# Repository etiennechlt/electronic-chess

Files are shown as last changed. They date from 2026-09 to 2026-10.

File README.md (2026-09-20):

# Échiquier électronique automatique à détection LC

Échiquier physique qui identifie chaque pièce (type et couleur) par un
résonateur LC passif logé dans sa base, arbitre les coups (roque,
prise en passant, promotion incluse), joue contre un moteur d'échecs
ou en ligne, et fonctionne sur batterie. Plateau fin de 44 cm et
21 mm d'épaisseur ; le déplacement des pièces par aimant sur portique
CoreXY est une base optionnelle qui se substitue au fond plat. Le
STM32G474 est maître, un ESP32-S3 sert de pont radio (WiFi, BLE vers
l'horloge à bascule séparée), le Raspberry Pi Zero 2 W est optionnel.

Architecture du système

## Principe de détection

Chaque pièce porte une bobine plate de 45 µH et un condensateur C0G
1 % de la série E12 qui fixe sa classe (12 valeurs, 217 à 613 kHz).
Chaque case excite en large bande par un front raide, écoute le
ringdown à travers l'entrefer, et classifie au plus proche voisin sur
des fréquences calibrées par pièce. L'aimant de pièce est en ferrite
dure, transparent au champ de mesure ; celui du chariot en néodyme.

Empilement vertical coté

Plan de fréquences des 12 classes

## Source de vérité unique

Toute valeur numérique du projet vient de
[`config/board.yaml`](config/board.yaml). Les grandeurs dérivées (les
12 fréquences, diamètres, courses, entrefer, autonomie) sont calculées
par la bibliothèque `chessboard_calc` et épinglées par les tests
contre la spécification. Le pas de case `p` est figé à 50 mm
(ADR 0010) ; tout reste paramétrique et le rapport compare toujours
40 et 50.

```bash
python3 -m venv .venv && .venv/bin/pip install -e ".[dev]"
.venv/bin/pytest                                        # les garde-fous
.venv/bin/python -m chessboard_calc report --pitch all  # tables dérivées
```

Le test de couloir (`tests/test_corridor.py`) verrouille la contrainte
`r_mobile + r_statique <= p/2` pour les 21 paires de classes : si une
édition du yaml la viole, la CI casse, car la partie se bloquerait dès
e2-e4.

## Plateau 8 x 8 (ADR 0010)

Un module plateau invariant (contreplaqué plus quatre quadrants 4 x 4
identiques, frontal analogique embarqué) posé dans une base fine ou,
plus tard, dans une base chariot avec le CoreXY et les ailes de
capture. Cerveau, carte puissance et cellules plates au fond de la
base, sur la même empreinte dans les deux bases. Horloge à bascule
séparée, en BLE. Choix et raisons dans la
[note 10](docs/notes/10-plateau-8x8-et-horloge.md).

| Plateau fin | Vue éclatée |
|---|---|
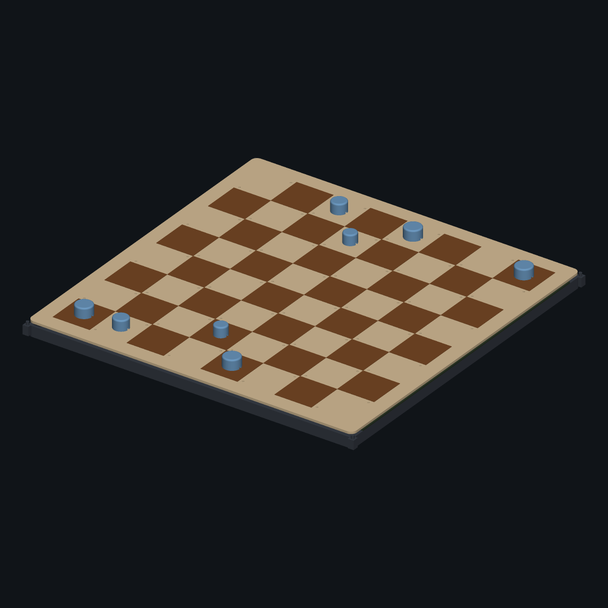
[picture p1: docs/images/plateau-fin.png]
Plateau fin
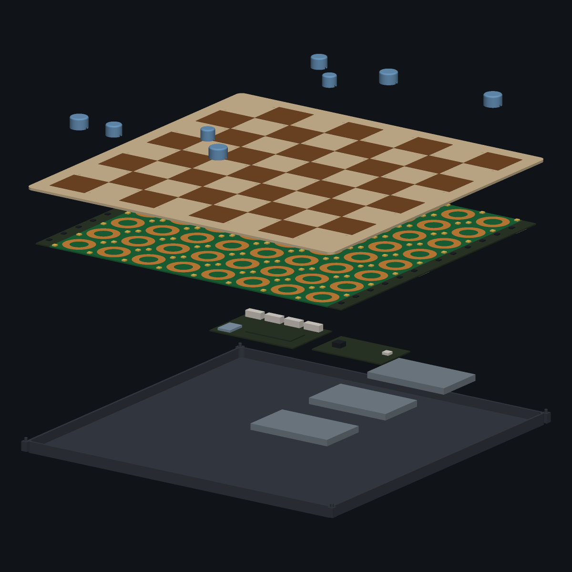
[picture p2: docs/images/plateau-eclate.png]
Vue éclatée
|  |  |

| Base chariot ouverte | Base chariot avec le module plateau |
|---|---|
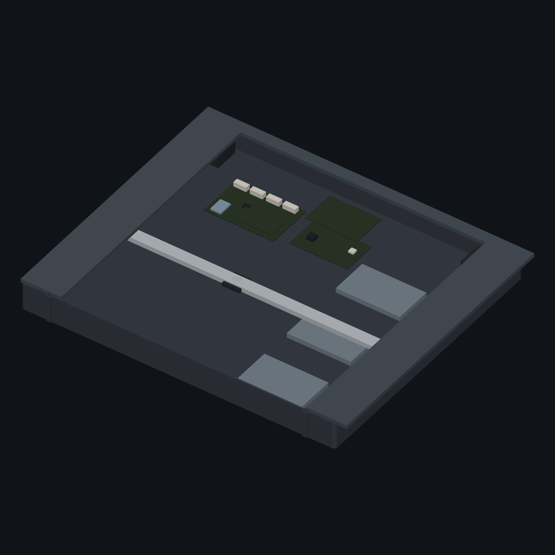
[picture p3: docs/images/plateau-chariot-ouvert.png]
Base chariot ouverte
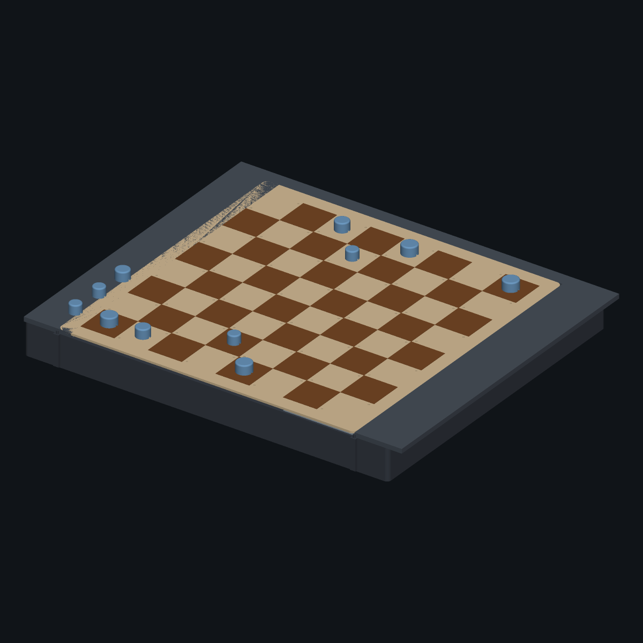
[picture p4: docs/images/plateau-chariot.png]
Base chariot
|  |  |

| Horloge à bascule | Horloge éclatée |
|---|---|
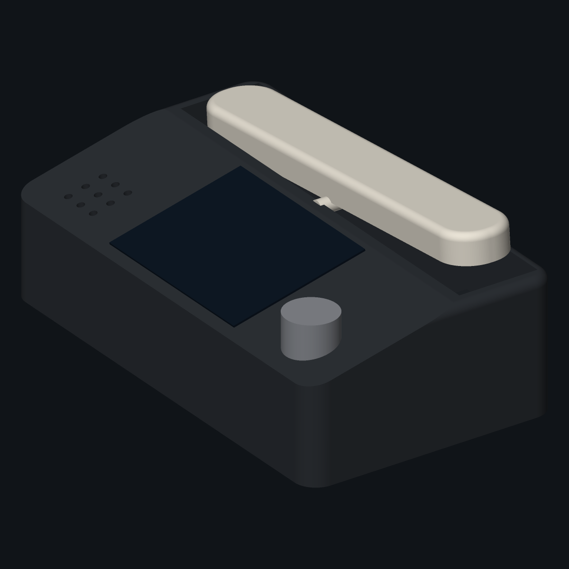
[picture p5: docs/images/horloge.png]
Horloge
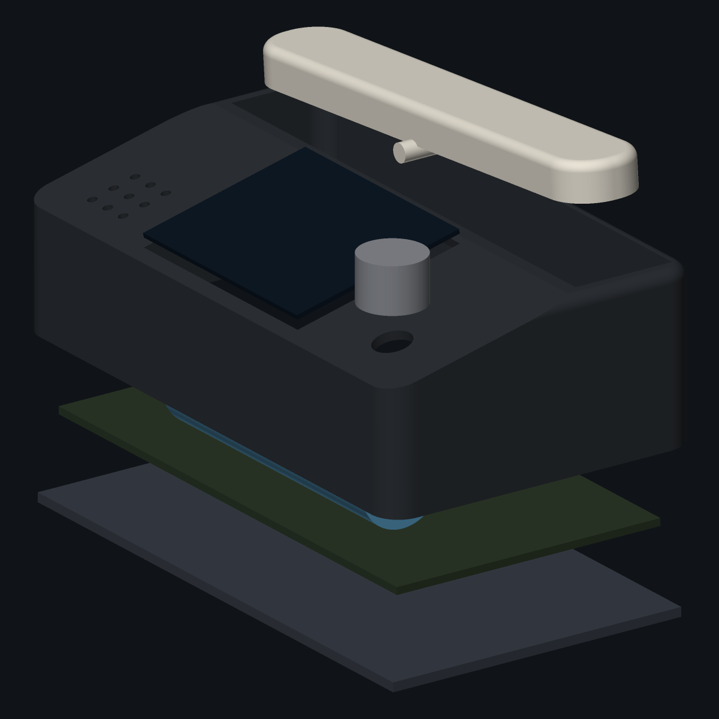
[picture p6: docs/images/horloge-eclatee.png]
Horloge éclatée
|  |  |

Vue 3D interactive (bases, éclaté, couches, noms au survol) :
`python mechanical/viewer.py` puis ouvrir `mechanical/exports/plateau-3d.html`.

| Quadrant 4 x 4 généré (`tools/quadgen`) |
|---|
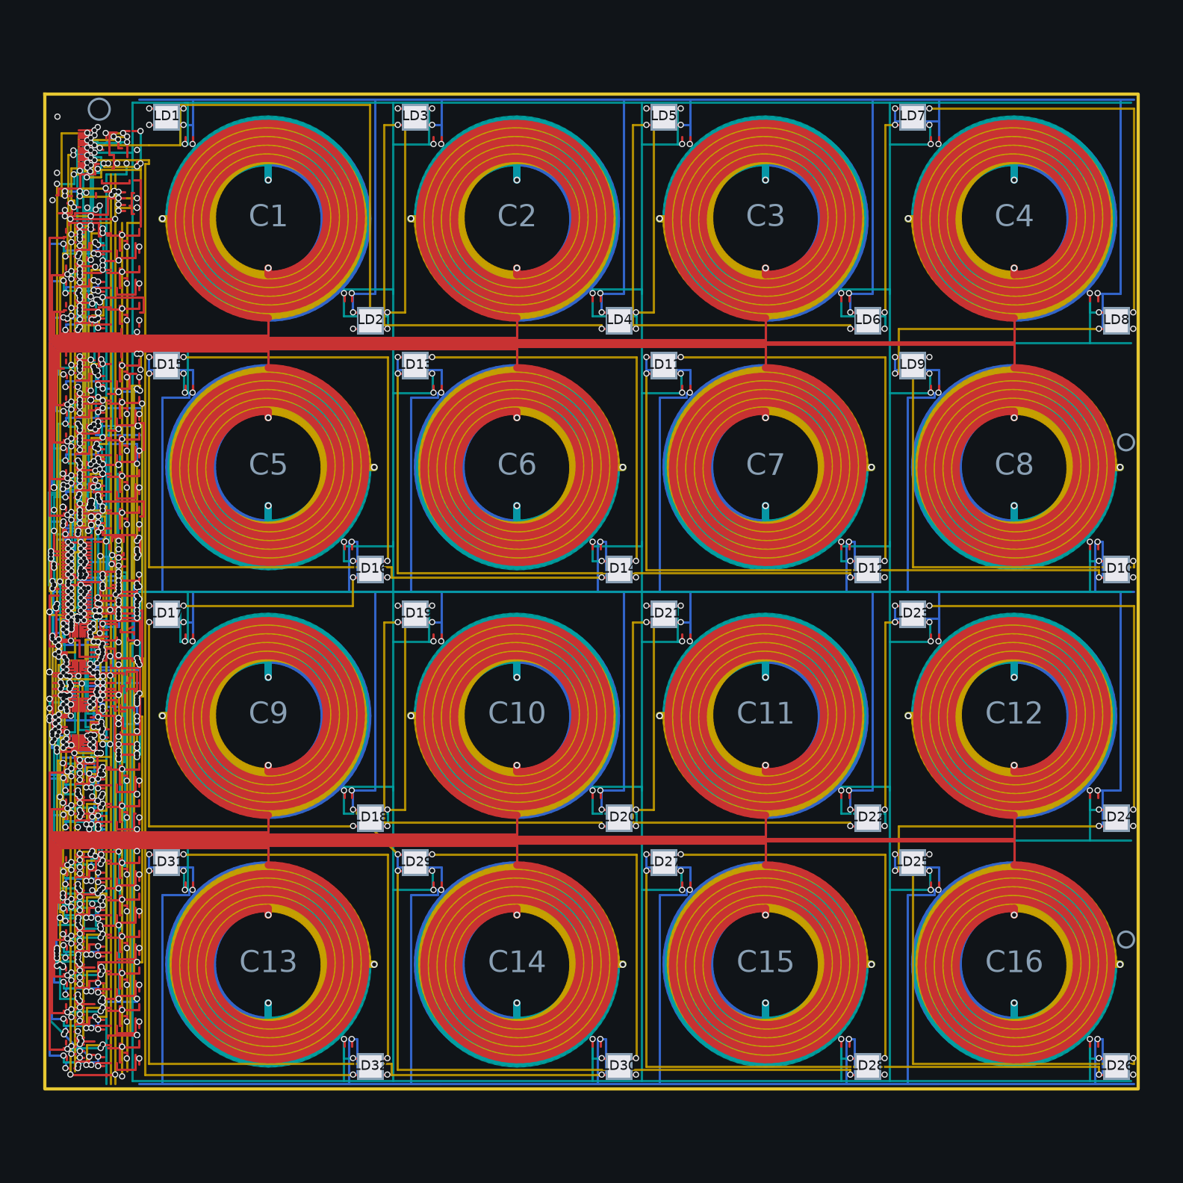
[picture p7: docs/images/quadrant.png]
Quadrant
|  |

Spirales, échappées vers la bande de frontal, 32 LED de camp et leur
distribution, connecteur FPC, et dans la bande de 20 mm le frontal
complet (16 cellules, deux ADG1607, décodeurs, chaîne AD8421 et
OPA2810) : [détails](hardware/quadrant/README.md). Le schéma est
dessiné feuille par feuille (fonction, composants et câblage dans la
[note 17](docs/notes/17-quadrant-fonction-et-cablage.md)) ; un
quadrant réduit 2 x 2, même circuit et même bus, sert de banc de mise
au point : [hardware/quadrant-2x2](hardware/quadrant-2x2/README.md).
Ce quadrant réduit et la [carte de banc](hardware/bench/README.md) qui
le pilote sont les deux cartes du plateau dont le routage est fermé,
donc les deux dont les gerbers sont commités
(`*-gerbers.zip`, produits par `tools/gerbers.py`, qui remplit les
pours avant de tracer et refuse toute carte à nets ouverts) : le banc
de la [note 20](docs/notes/20-tuto-banc.md) se commande tel quel. La
[carte analogique de maquette](hardware/mockup-2x2/analog-board/README.md),
gardée comme référence de la chaîne, est fermée elle aussi et porte
son archive. Ce qui se commande, avec quelles options et ce qu'il
manque aux autres cartes : la
[note 23](docs/notes/23-commande-jlcpcb.md). Ce qu'il faut acheter pour
monter le plateau (les 1 399 composants de quatre quadrants et d'un
cerveau, leur prix chez LCSC et chez Mouser, les paniers prêts à
téléverser) : la [fiche d'approvisionnement du plateau](docs/bom-plateau.md),
regénérée par `tools/bomagg.py`.

| Cerveau (STM32G474, 4 couches) | Puissance (3S, BQ24610, BQ76920) |
|---|---|
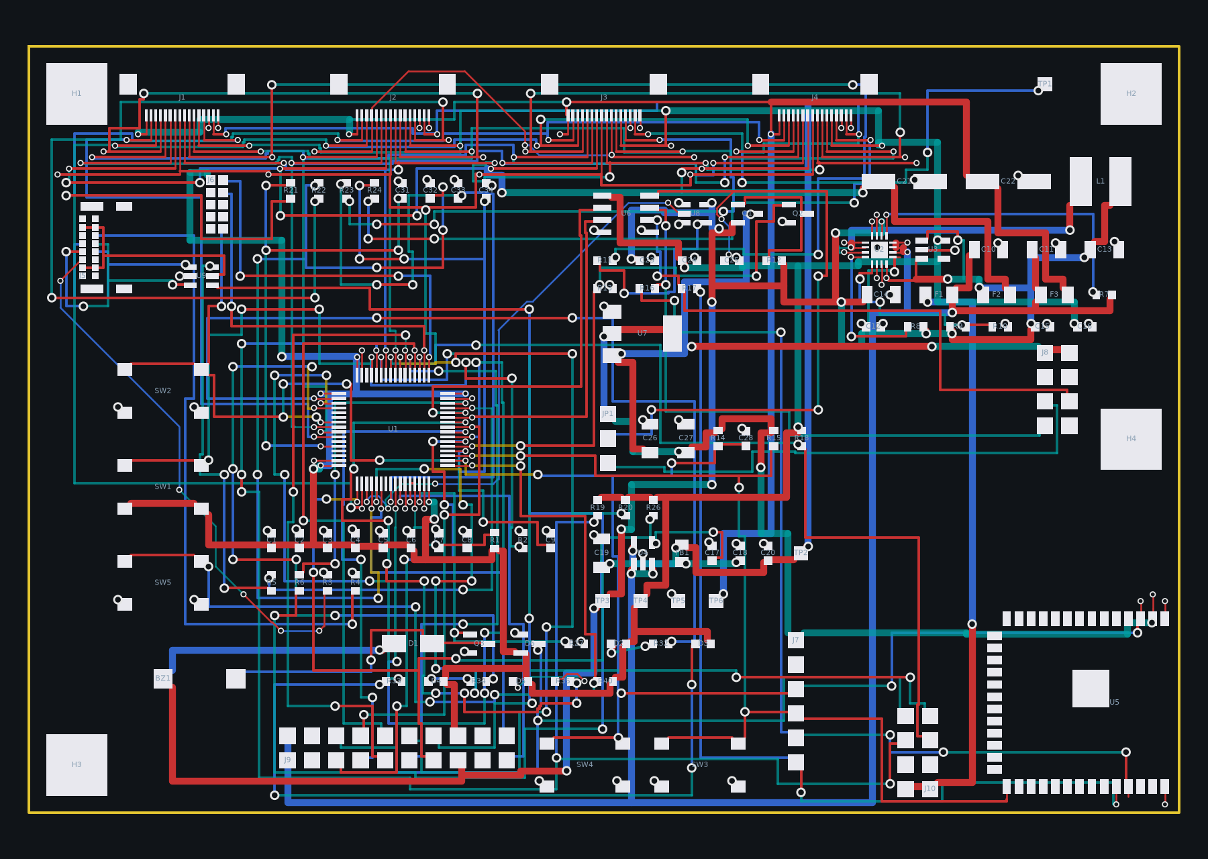
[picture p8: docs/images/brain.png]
Cerveau
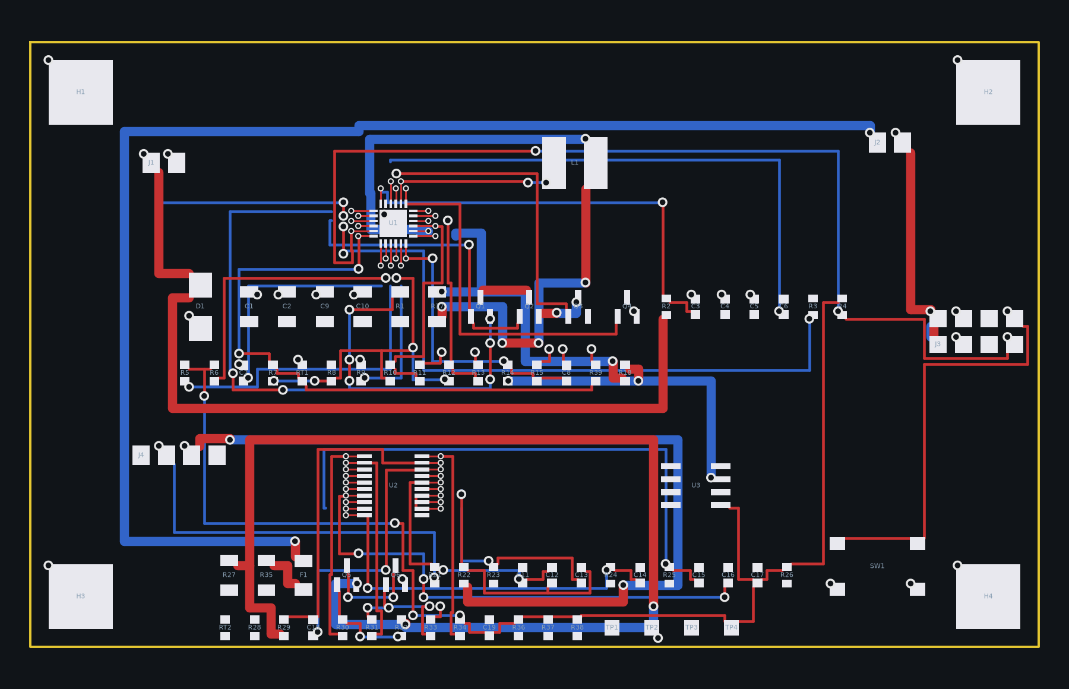
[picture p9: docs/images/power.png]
Puissance
|  |  |

| Moteurs (deux TMC2209, base chariot) | Horloge (ESP32-S3, 18650, écran) |
|---|---|
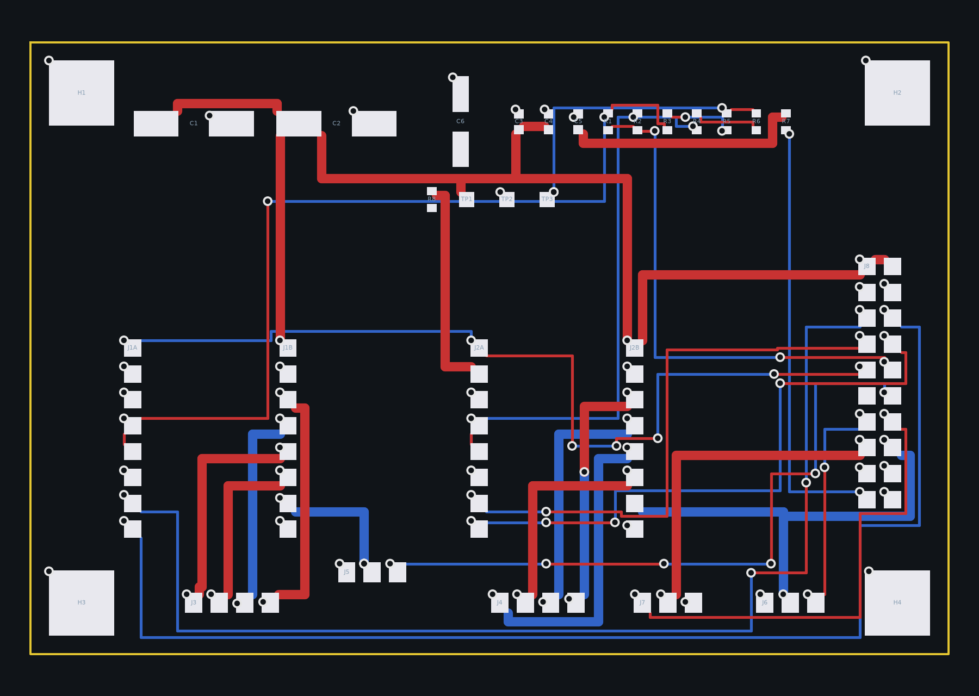
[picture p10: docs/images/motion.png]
Moteurs
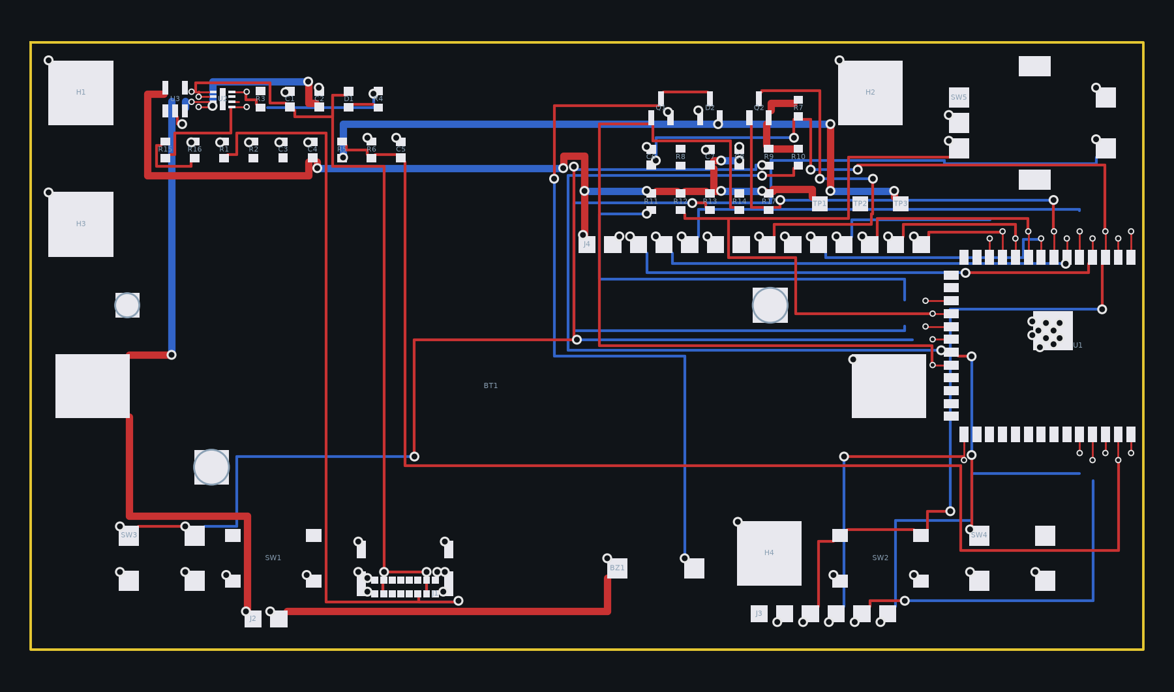
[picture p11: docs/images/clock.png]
|  |  |

Les quatre cartes sortent du générateur générique `tools/boardgen` ;
ce que le routeur laisse ouvert est listé dans le README de chaque
carte et résumé dans la [note 11](docs/notes/11-cartes-du-plateau.md).
Pour ouvrir, vérifier, simuler et tester : [note 13](docs/notes/13-revue-et-verification.md).

## Maquette 2 x 2 (phase 1, conçue, non construite)

La maquette a été conçue de bout en bout puis remplacée par le plateau
direct (ADR 0010) ; elle reste la référence de la chaîne analogique et
du routage ([guide](hardware/mockup-2x2/README.md),
[fiche d'approvisionnement](docs/bom-maquette.md)).

| Vue d'ensemble | Pièce de test éclatée |
|---|---|
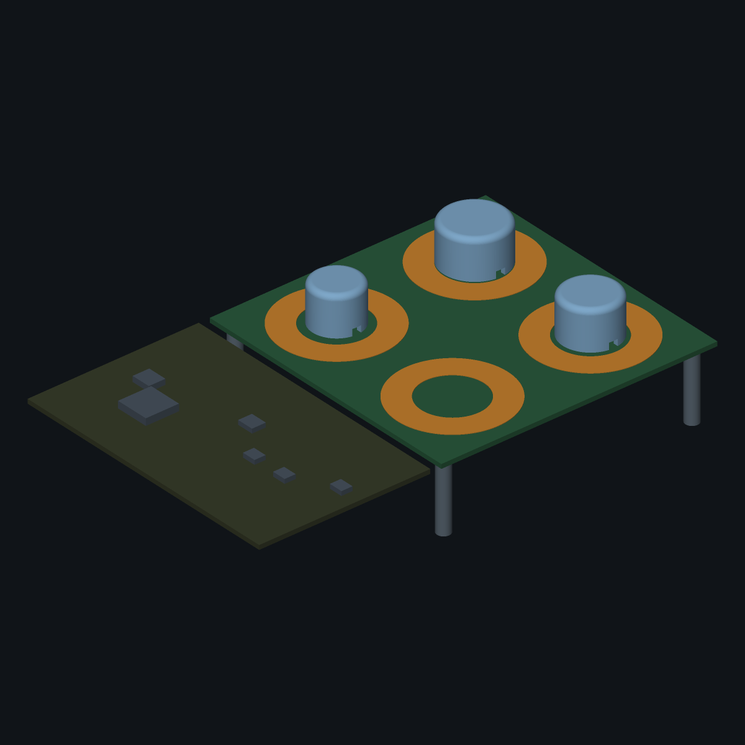
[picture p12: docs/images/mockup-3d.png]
Vue 3D de la maquette
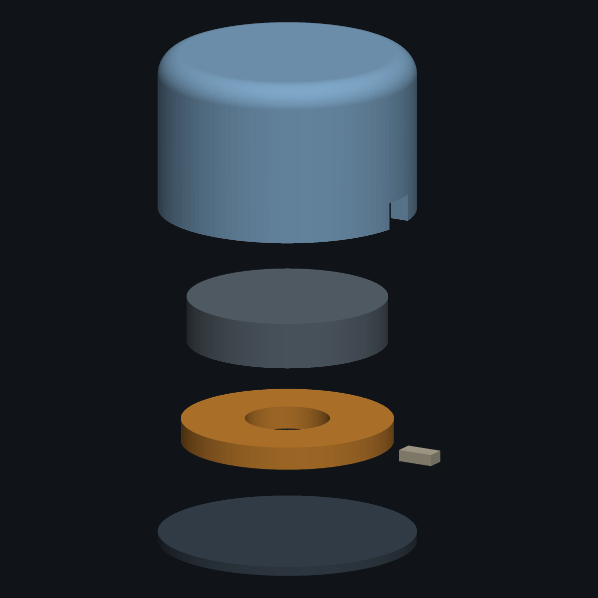
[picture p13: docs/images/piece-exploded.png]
Vue éclatée du puck
|  |  |

- **Carte bobines** (100 x 100, 4 couches, générée par
  [`coilgen`](tools/coilgen/)) : 4 spirales série de 5 tours par
  couche, 8 LED de camp WS2812B chaînées aux coins des cases (deux
  points lumineux par case à travers la surface en bois, ADR 0009).
  Son routage n'est pas fermé et son DRC porte 251 violations
  bloquantes : elle n'a pas d'archive de fabrication, et l'archive
  obsolète qu'elle portait a été retirée
  ([note 22](docs/notes/22-erreurs-de-conception.md), point 10),
  [détails](hardware/mockup-2x2/coil-board/README.md).
- **Carte analogique** (100 x 62, 2 couches, générée par
  [`analoggen`](tools/analoggen/)) : mux différentiel, AD8421,
  filtres Sallen-Key validés ngspice, buck forced-PWM contre LDO en
  cavalier, UART Pi isolée ; routage fermé, zéro élément non connecté
  et zéro erreur bloquante au DRC de KiCad, gerbers commités,
  [détails](hardware/mockup-2x2/analog-board/README.md).
- **Firmware** ([`firmware/board`](firmware/board/)) : les deux
  voies d'extraction du brief mesurées simultanément sur chaque
  ringdown, quatre quadrants par le bus de mux, calibration en flash,
  CSV sur le port série ; compile en CI. Pont radio et horloge en
  ESP-IDF ([`firmware/esp32`](firmware/esp32/)), protocole texte commun
  ([note 12](docs/notes/12-protocole.md)).
- **Mécanique** ([`mechanical/`](mechanical/README.md)) : plateau
  8 x 8 (module, bases, ailes), horloge, pucks de test, gabarits de
  bobinage, STL et STEP paramétriques, rendus et vue interactive.

| Carte bobines | Carte analogique |
|---|---|
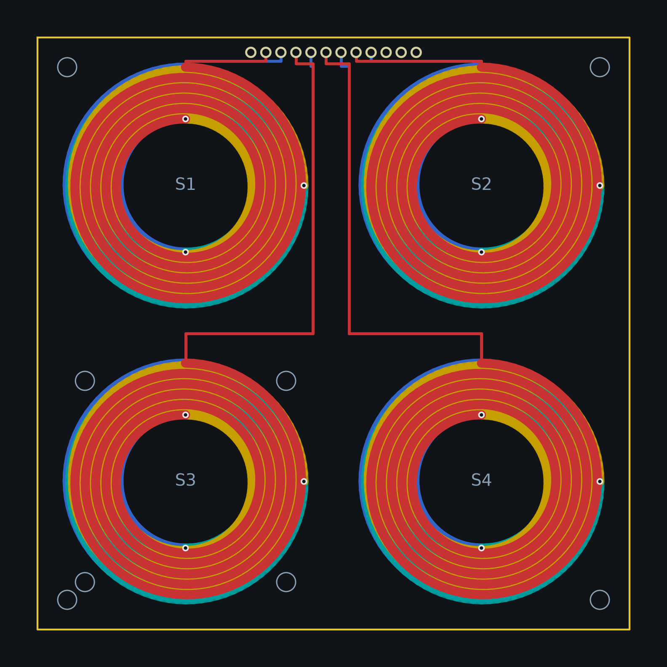
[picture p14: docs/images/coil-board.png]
Carte bobines
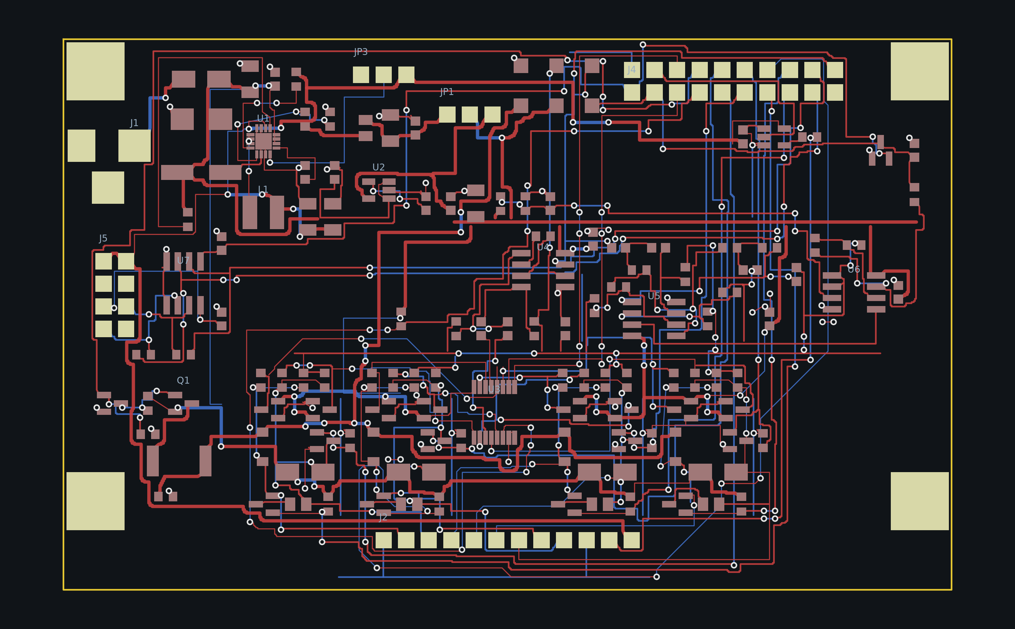
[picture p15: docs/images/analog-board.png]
Carte analogique
|  |  |

## Documentation

La base de connaissances du projet vit dans
[`docs/`](docs/README.md) : entrées par intention, notes de concepts
(mesure, architecture, générateurs, routeur, firmware), état de
référence, runbook de régénération et journal des décisions. Les
décisions formelles sont dans [`docs/adr/`](docs/adr/README.md).

## Arborescence

| Répertoire | Contenu | Phase |
|---|---|---|
| `config/` | `board.yaml`, source de vérité unique | 0 |
| `chessboard_calc/` | calculs paramétriques et garde-fous | 0 |
| `tools/coilgen`, `tools/analoggen` | générateurs KiCad des deux cartes de la maquette | 1 |
| `tools/drc.py`, `tools/plot.py`, `tools/gerbers.py` | DRC, tracés de faces et gerbers de fabrication, par le `pcbnew` de KiCad | 1 à 2 |
| `tools/fabcheck.py`, `tools/bomagg.py` | audit avant commande, et liste d'achat agrégée avec ses prix | 1 à 2 |
| `tools/quadgen`, `hardware/quadrant/` | générateur et projet KiCad du quadrant 4 x 4 | 2 |
| `tools/boardgen`, `hardware/{brain,power,motion,clock}/` | générateur générique et projets KiCad du cerveau, de la puissance, des moteurs et de l'horloge | 2 |
| `hardware/mockup-2x2/` | projets KiCad (`.kicad_pro` à ouvrir), gerbers, BOM, guides | 1 |
| `firmware/mockup/` | firmware Nucleo-G474RE (référence) | 1 |
| `firmware/board/` | firmware du cerveau : bus des quadrants, quatre ADC, 128 LED | 2 |
| `firmware/esp32/` | pont radio et horloge (ESP-IDF, NimBLE), protocole de la note 12 | 2 à 3 |
| `measurements/` | protocole, gabarits CSV, analyse | 1 |
| `mechanical/` | modèles CadQuery (plateau, horloge, pucks), rendus, vue 3D | 1 à 3 |
| `app/` | application, client Lichess sur le pont | 3 à 4 |

## État et décisions

Socle, calculs et CI livrés ; le plateau 8 x 8 est conçu directement
(ADR 0010) : yaml, géométrie, modèles 3D (STL et STEP dans
`mechanical/exports/`), quadrant complet, cerveau, puissance, moteurs et
horloge générés, firmware du cerveau compilé, pont et horloge écrits ;
premier lot de la phase 1 fait, la revue des cartes
([note 14](docs/notes/14-revue-des-cartes.md) : brochages relus, huit
erreurs corrigées dans les générateurs, DRC KiCad par `tools/drc.py`).
La suite est phasée : **phase 1, tout fonctionne sans chariot** (revue,
simulation, commande, bring-up, mesures, firmware, horloge, appli) ;
**phase 2, le chariot**. Feuille de route dans la
[note 07](docs/notes/07-etat-et-reste-a-faire.md). Les
décisions d'architecture et leurs justifications sont dans
[`docs/adr/`](docs/adr/README.md) ; conventions dans
[`CLAUDE.md`](CLAUDE.md) : code et commentaires en anglais,
documentation en français, aucune valeur dupliquée hors de
`board.yaml`.

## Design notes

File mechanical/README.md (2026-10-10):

# Mécanique (CadQuery)

Modèles paramétriques pilotés par `config/board.yaml`. Construction :

```bash
.venv/bin/python mechanical/build_all.py     # STL + STEP dans exports/ (versionnés)
.venv/bin/python mechanical/scenes.py        # rendus pour la doc (docs/images/)
.venv/bin/python mechanical/viewer.py        # vue 3D interactive (exports/plateau-3d.html)
.venv/bin/python mechanical/scenes.py --film-meshes media/pitch/commun/meshes  # maillages des films
```

Les films de présentation ([media/pitch](../media/pitch/README.md))
chargent les solides eux-mêmes : `--film-meshes` exporte en STL,
couche par couche et couleur par couleur, le plateau fin (base, trois
cellules, cartes, quatre quadrants, contreplaqué), la base chariot
sans son module et l'horloge avec sa barre à part, plus un
`manifest.json` (pivot de la barre). Ces maillages sont commités pour
rendre les films sans CadQuery ; les relancer après une modification
de la géométrie.

## Plateau 8 x 8 et horloge (ADR 0010)

- `plateau.py` : module plateau (contreplaqué à 128 points lumineux,
  quatre quadrants avec spirales, LED et bande de frontal), base fine,
  base chariot (CoreXY, ailes de capture, lisière), électronique sur
  empreinte commune, pièces. `assembly(cfg, gantry)` rend la liste des
  `Part` ; `exploded()` les écarte pour les vues éclatées.
- `clock.py` : boîtier de l'horloge à bascule (face inclinée, fenêtre
  d'écran, évidement de la barre, encodeur, grille, USB-C), fond,
  barre, bouton, intérieur. `horloge-boitier`, `horloge-fond` et
  `horloge-barre` s'impriment ; la barre est exportée à plat.
- `viewer_template.html` plus `viewer.py` : la vue interactive
  three.js, régénérée depuis les mêmes solides.
- Les cotes sont dérivées par `chessboard_calc/plateau.py` et
  épinglées par `tests/test_plateau.py` ; raisons dans la
  [note 10](../docs/notes/10-plateau-8x8-et-horloge.md).

Le rendu (`render_stl.py`) est un rasteriseur à tampon de profondeur
en numpy : occlusions exactes, sans OpenGL.

## Pièces de la maquette 2 x 2 (référence)

- `puck-<classe>-black` : pucks de test des 4 résonateurs bas de bande
  (pion, cavalier, fou, tour noirs). Alésage étagé par le dessous :
  logement bobine (2 mm), poche aimant ferrite ajustée, fente latérale
  pour le condensateur C0G et son accès de soudure. Impression tête en
  bas, 0,2 mm, sans support.
- `jig-core-d*` et `jig-washer-d*` : gabarits de bobinage, un par
  diamètre de bobine distinct. Le noyau donne le diamètre intérieur,
  les flasques l'épaisseur de 2 mm ; axe M3, encoche de sortie de fil.
  Monter le noyau dans une perceuse ou un petit tour, bobiner, coller
  au vernis, retirer la rondelle.
- `magnet-bracket-base` et `magnet-cup` : support d'aimant réglable
  sous la case S3 de la carte bobines. La platine se visse aux 4 trous
  M3 espacés de 34 mm, l'écrou central capture une vis M3 qui monte ou
  descend la coupelle porte-aimant (mesure 7 : distance de parking).

Quincaillerie : vis M3 x 8 (platine), M3 x 30 + 2 écrous (réglage),
entretoises M3 x 25 pour la carte bobines.

Les exports STL/STEP sont regénérés à la demande et ne sont pas
commités (`.gitignore`).

## Gabarit de perçage de la surface

`surface-template` reprend le contour de la carte bobines avec les
quatre trous de visserie et les deux points lumineux par case au
droit des LED de camp (ADR 0009). L'imprimer à plat (ou exporter le
DXF), le scotcher sur le contreplaqué et percer au travers ; les
points lumineux font `leds.light_hole_d_mm` (2,5 mm), à remplir
d'époxy translucide si l'on veut une surface affleurante.

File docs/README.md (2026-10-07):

# Documentation du damier électronique

Ce dossier est la base de connaissances du projet : tout ce qu'il faut
pour le comprendre, le régénérer, le commander et le reprendre à
froid. Les nombres font autorité dans `config/board.yaml` et dans les
tests qui les épinglent ; les documents expliquent, ils ne dupliquent
pas.

## Entrées par intention

- **Reprendre le projet à froid** : lire dans l'ordre
  [le principe de mesure](notes/01-principe-de-mesure.md),
  [l'architecture](notes/02-architecture-systeme.md),
  [le plateau 8 x 8 et ses choix](notes/10-plateau-8x8-et-horloge.md),
  [l'état et le reste à faire](notes/07-etat-et-reste-a-faire.md),
  puis le [journal](notes/09-journal.md) pour l'historique des choix.
- **Voir le plateau en 3D** : `python mechanical/viewer.py` génère la
  vue interactive (bases fine et chariot, éclaté, couches), les vues
  fixes sont dans `docs/images/plateau-*.png` et `horloge*.png`,
  méthode dans la [note 10](notes/10-plateau-8x8-et-horloge.md).
- **La maquette 2 x 2** (retirée du plan par l'ADR 0010, conservée
  comme référence de la chaîne analogique) : la
  [fiche d'approvisionnement](bom-maquette.md) et le
  [README de la carte analogique](../hardware/mockup-2x2/analog-board/README.md).
- **Le pilote simple** (07/10/2026) : une carte bobines passive
  100 x 100 et un shield soudé à la main, la
  [fiche du pilote](bom-pilote.md) dit ce qu'il réunit, ses trois
  options de shield et ce qu'il coûte.
- **Comprendre la mesure** :
  [principe](notes/01-principe-de-mesure.md), ADR
  [0001](adr/0001-lc-resonators-for-piece-identification.md) et
  [0007](adr/0007-frequency-extraction-dual-path.md), puis le
  [protocole M1 à M11](../measurements/protocol.md).
- **Savoir quoi faire ensuite** : la [note 07](notes/07-etat-et-reste-a-faire.md),
  feuille de route en deux phases (sans chariot d'abord, chariot ensuite).
- **Acheter les composants du plateau** : la
  [fiche d'approvisionnement du plateau](bom-plateau.md) donne la liste
  des 1 399 composants de quatre quadrants et d'un cerveau, ce qu'ils
  coûtent chez LCSC et chez Mouser, les neuf codes LCSC à corriger, les
  risques d'approvisionnement et les leviers chiffrés. Elle se regénère
  par `tools/bomagg.py`.
- **Commander les cartes chez JLCPCB** : la
  [note 23](notes/23-commande-jlcpcb.md) dit ce qui part et ce qui ne
  part pas, les fichiers et leur empreinte, les options écran par
  écran, la décision du cuivre interne, et ce qu'il manque pour passer
  un ordre d'assemblage plutôt que des cartes nues.
- **Ne pas refaire les erreurs déjà faites** : la
  [note 22](notes/22-erreurs-de-conception.md) reprend chaque erreur
  commise sur les cartes, ce qui l'a révélée, sa cause, sa correction
  et le contrôle automatique qui la rattrape désormais. À lire avant
  de toucher à un générateur ou de commander.
- **Baisser le coût des cartes** : la [note 16](notes/16-cout-des-cartes.md),
  état de la réflexion sur le quadrant et le format 100 x 100, avec
  les décisions à prendre avant tout devis.
- **Ouvrir, vérifier et tester les cartes** : la
  [note 13](notes/13-revue-et-verification.md) (KiCad, DRC, netlists,
  valeurs, simulation, commande, protocole de test) et le bilan de la
  revue des cartes, [note 14](notes/14-revue-des-cartes.md). L'état
  mesuré carte par carte, routage fermé ou non, est dans la
  [note 23](notes/23-commande-jlcpcb.md).
- **Savoir ce que le routage vaut devant les règles du métier** : la
  [note 21](notes/21-routage-et-regles-de-l-art.md) confronte les cartes
  générées aux règles de placement et de routage de la profession, avec
  la mesure de chacune par `tools/routing_audit.py` : ce qui est
  conforme, les écarts assumés (pas de plan continu sur In1 puisque la
  carte est le capteur, règle 2W dans une bande de 20 mm) et les deux
  points à corriger avant la commande.
- **Utiliser les skills embarqués** (analyseurs KiCad, SPICE, CEM,
  approvisionnement, mise en fabrication, commande JLCPCB, CadQuery) :
  la [note 15](notes/15-skills-embarques.md) dit lequel sert à quel
  lot et comment les mettre à jour.
- **Imprimer** : `python mechanical/build_all.py` écrit STL et STEP
  dans `mechanical/exports/` (non versionnés).
- **Comprendre le quadrant avant de le redessiner** : la
  [note 17](notes/17-quadrant-fonction-et-cablage.md), fonction, cycle
  de mesure, composants et câblage bloc par bloc.
- **Expliquer le projet à un non-spécialiste** : la
  [note 18](notes/18-facteur-q.md) (le facteur Q, avec les chiffres du
  projet), la [note 19](notes/19-cerveau-et-banc-nucleo.md) (le
  cerveau, le banc Nucleo, théorie contre réalité) et la
  [note 20](notes/20-tuto-banc.md) (le tuto du banc : quoi commander,
  comment assembler, comment tester) ; leurs schémas sont générés par
  `python -m docfig build`.
- **Envoyer ces explications à quelqu'un** : les mêmes trois textes
  existent en pages autonomes dans [`docs/pages/`](pages/), une par
  note, schémas embarqués et lisibles hors du dépôt :
  [le facteur Q](pages/facteur-q.html),
  [le cerveau et le banc](pages/cerveau-banc.html),
  [monter le banc](pages/tuto-banc.html). Elles sont générées par
  `python -m docfig pages`, des mêmes fonctions et du même yaml que les
  notes, donc jamais désynchronisées d'elles.
- **Modifier une carte** :
  [générateurs KiCad](notes/03-generateurs-kicad.md),
  [routeur et garanties](notes/04-routeur-et-garanties.md),
  [seeds et couloirs](notes/05-seeds-et-couloirs.md), puis le
  [runbook de régénération](notes/08-regenerer.md).
- **Toucher au firmware** : [note firmware](notes/06-firmware.md), le
  [README du firmware du cerveau](../firmware/board/README.md) (quatre
  quadrants) et celui de la [maquette](../firmware/mockup/README.md).
- **Lancer les mesures** : [protocole](../measurements/protocol.md),
  gabarits CSV et notebook dans `measurements/`.
- **Filmer le projet** : la série vidéo « Échec et Watt »
  ([bible](serie/README.md), [épisodes et scripts](serie/episodes.md),
  [tournage](serie/tournage.md), [montage](serie/montage.md)).

## Carte du dépôt

| Chemin | Contenu |
|---|---|
| `config/board.yaml` | source unique de toutes les valeurs |
| `chessboard_calc/` | calculs (fréquences, couloir, bobines, couplage, énergie) et CLI de rapport |
| `tools/coilgen/` | générateur complet de la carte bobines (spirales, LED, joint) |
| `tools/analoggen/` | générateur complet de la carte analogique (schéma, PCB routé, BOM, SPICE) |
| `tools/quadgen/` | générateur du quadrant 4 x 4 : spirales, échappées, LED, frontal complet (schéma, placement, routage) |
| `tools/boardgen/` | générateur générique et les quatre cartes du plateau : cerveau, puissance, moteurs, horloge |
| `tools/fabcheck.py` | audit de commande carte par carte : couches, empreinte de l'archive, couverture du BOM d'assemblage, verdict |
| `tools/docfig/` | schémas explicatifs de `docs/images/` (notes 18 et 19), dessinés depuis le yaml |
| `hardware/quadrant/`, `hardware/brain/`, `hardware/power/`, `hardware/motion/`, `hardware/clock/` | projets KiCad générés, BOM, placements, README de chaque carte |
| `hardware/quadrant-2x2/` | quadrant réduit 2 x 2 de mise au point, même circuit et même bus, schéma dessiné par feuilles |
| `hardware/bench/` | carte de banc, shield Nucleo-64 qui alimente et relie le quadrant 2 x 2 (note 19) |
| `hardware/mockup-2x2/` | artefacts générés : KiCad, gerbers, BOM JLC, guides |
| `firmware/board/` | firmware du cerveau (STM32G474, quatre quadrants, 128 LED) en CMSIS nu |
| `firmware/esp32/` | pont radio du cerveau et horloge (ESP-IDF, NimBLE), logique d'horloge testée sur PC |
| `firmware/mockup/` | firmware de la maquette Nucleo, référence |
| `mechanical/` | CadQuery : plateau 8 x 8 (module, bases, ailes), horloge, pucks, gabarits ; rendus et vue interactive |
| `measurements/` | protocole M1 à M11, gabarits CSV, analyse |
| `docs/adr/` | décisions d'architecture numérotées |
| `docs/notes/` | la présente base de connaissances |
| `docs/serie/` | série vidéo : bible, épisodes, tournage, montage |
| `.claude/skills/` | skills tiers embarqués (kicad-happy, pcba-design-skills, cad-skill), provenance dans `VENDORED.md` |
| `tests/` | une centaine de tests, dont le couloir bloquant en CI, l'empilement du plateau, le quadrant et la netlist de chaque schéma |

## Notes

| Note | Sujet |
|---|---|
| [01](notes/01-principe-de-mesure.md) | Principe de mesure : LC, ringdown, deux voies, classification |
| [02](notes/02-architecture-systeme.md) | Architecture système et budget de bruit |
| [03](notes/03-generateurs-kicad.md) | Générer du KiCad valide par script |
| [04](notes/04-routeur-et-garanties.md) | Le routeur maison et ses trois garanties |
| [05](notes/05-seeds-et-couloirs.md) | Seeds structurels et couloirs LED : la méthode |
| [06](notes/06-firmware.md) | Firmware : mesure, calibration, LED |
| [07](notes/07-etat-et-reste-a-faire.md) | État de référence et chemin vers le prototype réel |
| [08](notes/08-regenerer.md) | Runbook : tout régénérer |
| [09](notes/09-journal.md) | Journal des décisions et pivots |
| [10](notes/10-plateau-8x8-et-horloge.md) | Plateau 8 x 8, base interchangeable et horloge : les choix et leurs raisons |
| [11](notes/11-cartes-du-plateau.md) | Les cinq cartes du plateau : méthode, choix, revue avant fabrication |
| [12](notes/12-protocole.md) | Protocole plateau, pont radio, horloge (lignes texte, BLE) |
| [13](notes/13-revue-et-verification.md) | Ouvrir, vérifier, simuler, commander et tester les cartes |
| [14](notes/14-revue-des-cartes.md) | Revue des cartes de la phase 1 : constats, corrections, ce qui reste |
| [15](notes/15-skills-embarques.md) | Skills embarqués : lesquels, pour quel lot, comment les tenir à jour |
| [16](notes/16-cout-des-cartes.md) | Coût des cartes : quadrant, format 100 x 100, décisions à prendre avant de chiffrer |
| [17](notes/17-quadrant-fonction-et-cablage.md) | Quadrant : la fonction, les composants et leur câblage, base du schéma redessiné |
| [18](notes/18-facteur-q.md) | Le facteur Q, expliqué sans électronique |
| [19](notes/19-cerveau-et-banc-nucleo.md) | Le cerveau et le banc Nucleo, expliqués ; théorie contre réalité |
| [20](notes/20-tuto-banc.md) | Tuto du banc : quoi commander, quels composants, comment assembler et tester |
| [21](notes/21-routage-et-regles-de-l-art.md) | Le routage devant les règles du métier : conforme, écarts assumés, corrections |
| [22](notes/22-erreurs-de-conception.md) | Erreurs de conception des cartes, et le contrôle qui empêche chacune de revenir |
| [23](notes/23-commande-jlcpcb.md) | Commander chez JLCPCB : ce qui part, les options, ce qui manque pour l'assemblage |

Décisions formelles : [index des ADR](adr/README.md). Conventions de
contribution : `CLAUDE.md` à la racine (langue, typographie, source
unique, méthode).

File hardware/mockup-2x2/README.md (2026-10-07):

# Maquette 2 x 2 : commande, montage, mise en route

> Remplacée par l'ADR 0010 : la maquette n'est plus construite, le
> plateau 8 x 8 est conçu directement en quadrants. Ce dossier reste
> la référence de la chaîne analogique et du routage. Depuis le
> 07/10/2026 sa carte bobines, rendue passive, est la carte du
> **pilote simple** et la carte analogique son shield possible :
> voir la [fiche du pilote](../../docs/bom-pilote.md).

Deux cartes (ADR 0008) : la carte bobines (100 x 100, 4 couches,
passive) et la carte analogique (100 x 62, 2 couches, assemblée). Le
MCU est une Nucleo-G474RE du commerce reliée en nappes Dupont.

## 0. Ouvrir les cartes dans KiCad

Chaque carte a son fichier projet `.kicad_pro` à côté du `.kicad_pcb`,
généré en même temps que lui : c'est ce fichier qu'on ouvre, KiCad ne
sachant pas ouvrir une carte seule depuis son gestionnaire de projet.

```bash
kicad hardware/mockup-2x2/analog-board/analog-board.kicad_pro
kicad hardware/mockup-2x2/coil-board/coil-board.kicad_pro
```

Sous macOS ou Windows, double clic sur le `.kicad_pro` (ou KiCad,
Fichier, Ouvrir un projet). La carte s'ouvre avec les règles du
générateur déjà en place : classe de nets, largeurs de piste et vias
proposés au routage, minima du DRC. Le projet de la carte analogique
associe aussi son schéma, ouvrable depuis le même gestionnaire.

Trois choses à savoir :

- Les fichiers sont au format KiCad 7. KiCad 8 ou 9 les ouvre et
  propose la conversion au premier enregistrement.
- Symboles et empreintes sont embarqués dans les fichiers : aucune
  bibliothèque à installer, aucune table de bibliothèques à régler.
- KiCad réécrit le `.kicad_pro` en enregistrant (état des fenêtres) et
  crée un `.kicad_prl` local, ignoré par git. Une régénération remet
  le projet dans son état canonique.

Sans KiCad : les rendus `docs/images/analog-board.png` et
`docs/images/coil-board.png`, ou les zip de gerbers dans une
visionneuse.

## 1. Commander

### Carte bobines (8 à 15 EUR les 5, plus l'option cuivre interne)

`sh hardware/mockup-2x2/coil-board/export.sh` regénère la carte et
produit `coil-board-gerbers.zip` (commité avec son empreinte). JLCPCB :
4 couches, 1,6 mm, 1 oz externe, cuivre interne 1 oz en option (note 23,
paragraphe 3.1), pas d'assemblage : la carte est passive, les LED sont
coupées par `leds.fitted` dans le yaml.

### Carte analogique (~60 EUR les 5 dont 2 assemblées)

`analog-board/` contient le projet KiCad, `jlc-bom.csv` et
`jlc-cpl.csv`. JLCPCB : 2 couches, 1,6 mm, assemblage face top.
Important : les codes LCSC du BOM sont des candidats plausibles saisis
hors ligne ; l'outil de commande JLC rapproche aussi par référence
fabricant (MPN) et signale tout écart : vérifier chaque ligne dans
leur prévisualisation avant de payer, en particulier TPS62150RGTR,
AD8421ARZ, OPA2810IDR, 74HCT4052PW, ADuM1201ARZ. Les composants
introuvables en assemblage (souvent l'AD8421) se commandent chez
Mouser ou DigiKey et se soudent à la main (SOIC, facile).

### Le reste (~70 EUR)

Voir `docs/bom-maquette.md` : Nucleo-G474RE, condensateurs C0G des
résonateurs, fil émaillé, aimants ferrite et N42, contreplaqué sec 3 à 6 mm,
feutre, visserie, impression des pièces de `mechanical/`.

## 2. Assembler

1. Carte analogique : souder les traversants (jack, barrettes J2 J4
   J5, JP1 JP3) ; laisser R66 et R67 non montées (elles court-circuitent
   l'isolateur UART).
2. Carte bobines : souder la barrette coudée 1 x 10 mâle pointant vers
   le nord ; entretoises M3 x 25 aux quatre coins.
3. Emboîter la barrette dans le connecteur femelle coudé J2 de la
   carte analogique : les deux cartes sont coplanaires, broche 1 sur
   broche 1 (x = 38,57 mm sur les deux).
4. Support d'aimant : visser la platine sous S3, monter la coupelle
   sur sa vis M3.
5. Bobiner les 4 résonateurs (gabarits imprimés, fil 0,25 mm, tours
   par classe donnés par `python -m chessboard_calc report`), souder
   chaque condensateur C0G, coller bobine et aimant dans les pucks,
   feutre dessous.
6. Percer la planche de contreplaqué avec le gabarit `surface-template`
   (trous de visserie et points lumineux des LED), puis la poser sur les
   entretoises au dessus de
   la carte bobines.

## 3. Câbler la Nucleo

Nappes Dupont femelle-femelle de J4 vers la Nucleo (UM2505), table
générée depuis `config/board.yaml` (section `nucleo_pins`) :

| J4 | Signal | Nucleo |
|---|---|---|
| 1 | 3V3 | 3V3 |
| 2, 4, 19 | GND | GND |
| 3 | AMP_OUT | A0 (PA0), en pont vers A1 (PA1) pour la voie B |
| 5 | MUX_A0 | D3 (PB3) |
| 6 | MUX_A1 | D4 (PB5) |
| 7 | MUX_INH | D5 (PB4) |
| 8 | PULSE_EN | A2 (PA4) |
| 9 a 12 | DRIVE1..4 | D11 (PA7), D12 (PA6), D14 (PB9), D15 (PB8) |
| 13 a 16 | DAMP1..4_N | D6 (PB10), D7 (PA8), D9 (PC7), D10 (PB6) |
| 17 | MCU_TX | D8 (PA9) |
| 18 | MCU_RX | D2 (PA10) |
| 20 | INA_OUT | libre (oscilloscope) |

## 4. Mise en route

1. Flasher `firmware/mockup` (`make`, copier le .bin sur le lecteur
   NUCLEO). Console VCP 921600 bauds.
2. Alimenter le 12 V (JP1 côté LDO pour commencer, JP3 côté FPWM).
3. `h` puis `s` : quatre lignes CSV. Sans puck, amp_mv doit rester
   faible ; poser un puck doit faire apparaître sa fréquence.
4. Vérifier la voie B au générateur de fonctions sur AMP_OUT (voir
   `firmware/mockup/README.md`, points à vérifier).
5. Dérouler `measurements/protocol.md`.

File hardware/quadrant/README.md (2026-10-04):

# Quadrant 4 x 4 : carte de détection du plateau 8 x 8

Quadrant 4 x 4

Carte générée par `tools/quadgen` depuis `config/board.yaml`
(ADR 0010). Quatre exemplaires identiques dallent l'aire de jeu ; la
paire de droite est montée tournée de 180 degrés, ce qui laisse la
diagonale des LED inchangée et met la bande de frontal au bord extérieur.

## Ce que contient la carte

- 220 x 200 mm, 4 couches : 20 mm de bande de frontal à l'ouest
  (`plateau.quadrant.front_end_strip_mm`, couverte par la bordure de
  bois de même largeur), puis quatre colonnes de cases de 50 mm, soit
  4 p plus la bande sur 4 p.
- 16 spirales de détection (4 couches en série, 5 tours par couche,
  piste 1,6 mm), bornes empilées au nord des rangées impaires et au
  sud des rangées paires : chaque paire de rangées s'échappe dans le
  couloir qui les sépare (« bande »), huit voies par bande, vers les
  cellules du frontal, borne A sur F.Cu et borne B sur B.Cu.
- 32 WS2812B aux coins NO et SE de chaque case, un 100 nF chacune,
  vias latérales, chaîne de données sur In1 en serpentin (rangée 0 vers
  l'est, rangée 1 vers l'ouest, et ainsi de suite), grille 5 V sur
  In2, masse sur B.Cu (bords nord et sud, couloir médian) reliée au
  bus de la bande sur In1. Chaîne et retours sont routés par un A* sur
  grille de 0,2 mm contre tout le cuivre déjà posé.
- Connecteur FPC 16 broches 0,5 mm (Hirose FH12, 1,4 mm de haut, câble
  sortant à l'ouest), brochage dans `plateau.quadrant.link.pinout`.
- Trou de pion de centrage en bas de la bande, deux trous de fixation
  M3 au bord est, dans les zones libres de vias LED.

Le contrôle d'isolement exact (shapely) tourne à chaque build et le
projet KiCad porte les règles du générateur, vias d'éventail comprises ;
le DRC de KiCad se lance par `tools/drc.py` (module `pcbnew`, voir la
[note 14](../../docs/notes/14-revue-des-cartes.md)) ou après ouverture.
Le build échoue si une route de la chaîne LED, un retour d'alimentation
ou un net du frontal reste ouvert : la liste imprimée est ce qu'il reste
à fermer dans pcbnew.

## Le frontal de la bande

- 16 cellules de 7,4 mm en face de leur bobine, réparties de part et
  d'autre de chaque bande d'échappée : bleed 10 k vers VREF, 330 ohms
  et BAV99W (SOT-323) devant le mux, diode de bus B5819W et AO3400A
  d'excitation, SS34FL de roue libre vers VIN (SOD-123F, 1 mm de haut),
  B5819W de roue libre depuis la masse (point 1 de la
  [note 17](../../docs/notes/17-quadrant-fonction-et-cablage.md) : le
  courant de la bobine se referme par elle quand le N-FET s'ouvre, et
  R7 de 470 ohms coupe le rail en moins d'une microseconde), AO3401A et
  680 ohms d'amortissement pilotés directement par le décodeur (point 2,
  plus de rappel vers VIN), pulldown de grille 0402. Les colonnes de la cellule sont
  empilées à partir des cours réelles des empreintes et contrôlées
  contre le pas de 7,4 mm. L'entrée A arrive sur F.Cu à y - 0,6,
  l'entrée B sur B.Cu à y + 0,6 avec sa via.
- Zone médiane de 43,8 mm : 74HC4514 (excitation, inhibé par PULSE_EN
  à travers un 74LVC1G04) et 74HC154 (amortissement, validé par
  DAMP_EN_N), deux ADG1607 (bobines 1 à 8, 9 à 16, sorties en
  parallèle, un enable chacun, bus d'adresses A0..A2 partagé), AD8421
  G = 20, OPA2810 en Sallen-Key passe-haut et passe-bas, OPA2810 en
  tampon VREF et étage de sortie, écrêtage vers 3V3 et RC de sortie.
- Zone du milieu (43,8 mm entre les deux groupes de cellules, ancrée
  aux bandes d'échappée), du haut vers le bas : les deux décodeurs
  TSSOP empilés (le 74HC154 tourné de 180 degrés, adresses à l'ouest,
  sorties des bobines 1 à 11 à l'est, du côté des grilles), chacune de
  leurs vingt-quatre broches prolongée sous le boîtier jusqu'à un via
  (quatre colonnes au pas double des pastilles) ; le mux des bobines 1
  à 8, tourné de 270 degrés, ses seize entrées dessinées à la main en
  éventails (voies au pas de 0,6 mm, vias dans deux colonnes par côté) ;
  les deux amplificateurs côte à côte, broches échappées sous le
  boîtier ; le mux des bobines 9 à 16 et ses éventails. Tous les
  boîtiers à vias sont dans la bande ouest ; les passifs occupent la
  bande est, entre le rail 3V3 et le bord, par affinité.
- Zone du connecteur (25,7 mm) : FPC 16 broches, commutateur de rail
  d'impulsion (AO3401A, AO3400A, et la 10 ohms 2010 à côté), réserve
  10 µF, l'étage de sortie (OPA2810 avec ses résistances et son
  condensateur) pour que seul le signal filtré traverse la bande ; le
  point de test de sortie y reste, ceux de VREF et du bus d'excitation
  sont au pied de la bande, à côté de leur bus.
- Bus sur In1 côté est : 5VA, VREF, DRIVE_BUS, VIN et GND ; 3V3 et
  5V_LED sur In2. Les lignes de mesure M{k} vers les mux et les lignes
  de grille des décodeurs sont routées par le routeur A* multicouche
  depuis les vias dessinés à la main, un rip-up cherche le mur de
  chaque net resté en morceaux, puis un contrôle d'isolement exact
  valide toute la carte.
- Les vias d'empilement des bobines sont décalées radialement hors des
  bandes de spires (1,3 mm dans le creux ou au-delà du rayon extérieur,
  reliées par un tronçon radial) : posées sur le rayon même, elles
  recouvraient les spires des autres couches et court-circuitaient la
  bobine. La dernière jonction (In2 vers B.Cu) descend à 3,5 mm dans le
  creux et son tronçon radial porte le « net tie » (`quadgen:COIL_TIE`) :
  couches 1 à 3, vias et début du tronçon sur C{k}_A, deux pastilles
  B.Cu carrées qui se touchent, puis la suite du tronçon, l'arc
  d'entrée, la spirale de la couche 4 et l'échappée B sur C{k}_B, le
  tout à la largeur de spire. Aucun cuivre d'un net ne recouvre un trou
  de l'autre, ce que le DRC de KiCad exige même dans un net tie. Le
  schéma montre le même NT{k}.

Sorties du build : projet KiCad avec son schéma dessiné (feuille racine
`quadrant.kicad_sch` avec J1 et les blocs, puis `rails`, `cells-1` à
`cells-4`, `select`, `chain`, `leds`, fils tracés entre les composants,
fonction et câblage dans la note 17 ; aperçus dans le
[README du 2 x 2](../quadrant-2x2/README.md)), `bom.csv`, `jlc-bom.csv`
(lignes avec code LCSC), `jlc-cpl.csv`, `chain-spice.cir`.

## Régénérer

```bash
PYTHONPATH=tools .venv/bin/python -m quadgen build --render docs/images/quadrant.png
```

## Résultat du build

Généré par `python -m quadgen build` le 04/10/2026, avec les éventails
et les échappées dessinés à la main, le rip-up par recherche du mur et
la passe de finition partagée
([note 04](../../docs/notes/04-routeur-et-garanties.md)) :

| Bobines | LED | Segments | Vias | Raccords de la passe | Routes LED et alimentation ouvertes | Nets ouverts | Défauts d'isolement |
|---|---|---|---|---|---|---|---|
| 16 | 32 | 33171 | 946 | 15 | 0 | 24 | 0 |

Le build commité du 20/09 en laissait 47 ; les éventails des
multiplexeurs, les échappées sous boîtier des décodeurs et des
amplificateurs, l'étage de sortie ramené à la liaison, le 74HC154
tourné et le rip-up par recherche du mur ont fermé le reste, dans
l'ordre raconté par la note 04. Ce qui reste ouvert : douze lignes de
grille (DRIVE 2, 3, 10, 11, 12, 14, 15 et DAMP 2, 3, 9, 10, 16), neuf
lignes M (bobines 1, 2, 3 et 5 des deux côtés, 14 B), le retour du
filtre vers l'étage de sortie (LP_OUT), la référence en huit pièces et
un îlot du plan de masse. La cause est mesurée
voie par voie dans la note 04 : dans les rangées de la dernière cellule
de la bande 0 et sous les décodeurs, la bande de 20 mm offre à peu près
autant de voies que de lignes à faire passer, et un routeur séquentiel
n'emplit pas un couloir ; le rip-up trouve le mur de chaque net, deux à
cinq nets, et une levée sur deux est défaite faute de place pour ce
qu'elle soulève. Les options restantes (autoroutes à la main pour les
cellules lointaines, bande de 24 mm, six couches, cellule allégée) sont
des décisions de conception.

Aucune archive de fabrication : `tools/gerbers.py` refuse une carte au
routage ouvert.

DRC KiCad 7 (`tools/drc.py`, zones remplies) : 686 signalements, 31 éléments non connectés (les 24 nets ouverts ci-dessus), erreurs restantes : aucune ; avertissements sans effet sur la fabrication : lib_footprint_issues 199, silk_over_copper 199, silk_overlap 199, via_dangling 60, track_dangling 28, silk_edge_clearance 1. Le contrôle d'isolement exact du générateur ne signale aucun défaut. Les vias d'éventail et d'échappée font 0,45 mm (perçage 0,2 mm), dans les capacités standard de JLCPCB, à confirmer sur le devis.

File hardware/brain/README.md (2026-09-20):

# Cerveau : carte principale du plateau

Carte cerveau

Carte générée par `tools/boardgen` (module `brain`) depuis
`config/board.yaml` (ADR 0010). 120 x 80 mm, 4 couches : F.Cu
composants et signaux, In1 plan de masse, In2 alimentations et
signaux longs, B.Cu signaux. Elle vit au fond de la base, sur
l'empreinte commune aux deux bases.

## Blocs

- **MCU** : STM32G474RE soudé (LQFP-64), sans quartz (HSI plus CRS sur
  l'USB), boutons RESET et BOOT, connecteur SWD 2 x 5 au pas 1,27 mm
  (SWO et TDI laissés libres), USB-C en périphérique (USBLC6-2 en
  protection, 5,1 k sur CC, VBUS non utilisé : la carte se nourrit du
  pack). Le tableau des broches est `plateau.brain.mcu_pins` dans le
  yaml, relu contre la fiche technique dans la
  [note 14](../../docs/notes/14-revue-des-cartes.md) (quatre entrées ADC
  sur quatre convertisseurs distincts, PB8 sert de BOOT0, PG10 de NRST).
- **Liens quadrants** : quatre connecteurs FPC 16 broches (même
  brochage que le quadrant), bus d'adresses et d'enables partagé,
  quatre sorties analogiques vers quatre ADC à travers 49,9 ohms et
  1 nF, chaîne LED sérialisée d'un quadrant au suivant, tampon
  74AHCT1G125 à la source.
- **Alimentation** : fusible d'entrée, buck TPS62130 3 A à 2,5 MHz en
  PWM forcé (DEF haut) pour le 5 V, AP2112K pour le 3,3 V logique,
  LP2985 plus perle de ferrite pour l'îlot 5VA des quadrants, rail
  12 V d'impulsion (VIN) fusé avec sa réserve de 100 µF, rail LED fusé.
- **Communication** : UART tamponnée par un ADuM1201 (GND2 sur la masse
  commune : pas d'isolation galvanique tant que le module est sur la
  carte), TXD0 du module vers l'entrée VIA, sortie VOB vers RXD0, load
  switch P-FET sur le 5 V du module, régulateur AMS1117 pour
  l'ESP32-S3-WROOM-1, cavalier JP1 pour alimenter le côté module depuis
  l'ESP32 ou le Pi, embase Pi 2 x 4, embase de programmation ESP 1 x 6,
  boutons BOOT et EN. Le module est au bord est, son antenne dépasse de
  6 mm de la carte et sa zone de dégagement (la cour KiCad, 48 x 41 mm)
  occupe le coin sud-est : le quatrième trou de fixation est remonté à
  mi-hauteur du bord est.
- **Liens** : IDC 2 x 10 vers la carte moteurs (VBAT, STEP, DIR, EN,
  UART TMC, fins de course, servo, 5 V, 3,3 V), 2 x 4 vers la carte
  puissance (VBAT, I2C, état de charge, touche de réveil).
- **Interface** : buzzer 12 mm sur transistor, quatre LED d'état,
  bouton utilisateur, points de test.

## Hygiène de signal

Le plan de masse In1 est continu ; les sorties analogiques arrivent au
bord nord avec leur filtre RC juste devant le MCU ; le module radio est
au coin sud-est, le plus loin des connecteurs de quadrant ; le buck est
au coin nord-est avec sa boucle de commutation courte. Le routeur pousse
les longs signaux sur les couches internes (coût majoré sur F.Cu et
B.Cu) et ne perce jamais de via dans le trou d'une pastille traversante.
Point ouvert de la revue : le LP2985 de l'îlot 5VA (SOT-23-5) dissipe
0,5 W depuis VBAT pour les quatre frontaux, un boîtier à pad thermique
est proposé.

## Régénérer

```bash
PYTHONPATH=tools .venv/bin/python -m boardgen build brain --render docs/images/brain.png
```

Le contrôle d'isolement exact tourne à chaque build ; les nets que le
routeur n'a pas fermés sont listés et restent à finir dans pcbnew.

## Résultat du build

Généré par `python -m boardgen build brain` le 20/09/2026 :

| Composants | Segments | Vias | Raccords de la passe | Nets fermés | Nets ouverts | Défauts d'isolement |
|---|---|---|---|---|---|---|
| 113 | 1528 | 476 | 6 | 92 | 0 | 0 |

Ce qui a fermé la carte, dans l'ordre où il a fallu le trouver
([note 04](../../docs/notes/04-routeur-et-garanties.md)) :

- les éventails des quatre liens FPC dessinés à la main (voies de
  0,3 mm en escalier sur la face avant, un petit via au bout de chacune,
  les masses descendues au plan à leur moignon), la bande médiane
  descendue sous eux ;
- le bus des quadrants, les alimentations, VBAT, les quatre sorties
  analogiques et les deux lignes UART de l'isolateur routés en premier,
  quand la carte est vide ;
- le haul VBAT dessiné à la main sur la face arrière, du lien moteurs
  au fusible F1 par le bord sud puis une colonne à l'ouest du lien
  puissance ;
- chaque LED d'état placée à côté de sa résistance ;
- les masses descendues au plan avant les signaux, une garde de 0,1 mm
  autour des pastilles CMS ;
- le rip-up et reroutage des nets murés, puis la passe de finition
  partagée (six raccords).

DRC KiCad 7 (`tools/drc.py`, zones remplies) : 220 signalements, aucun élément non connecté, aucune erreur ; avertissements sans effet sur la fabrication : lib_footprint_issues 113, silk_overlap 52, via_dangling 27, silk_over_copper 23, silk_edge_clearance 3, track_dangling 2. Le contrôle d'isolement exact du générateur ne signale aucun défaut. Les vias d'éventail des boîtiers fins font 0,45 mm (perçage 0,2 mm), dans les capacités standard de JLCPCB.

## Fabrication

`brain-gerbers.zip` (quatre couches de cuivre, masques, sérigraphies,
pâte, contour, perçages PTH et NPTH, fiche de travail) et son
empreinte `brain-gerbers.sha256`, produits par
`/usr/bin/python3 tools/gerbers.py hardware/brain/brain.kicad_pcb` ;
`sha256sum -c brain-gerbers.sha256` dans ce dossier vérifie que
l'archive est celle de la carte commitée. Commande et options du
formulaire dans la [note 23](../../docs/notes/23-commande-jlcpcb.md) :
120 x 80 mm, 4 couches, ENIG (LQFP au pas de 0,5 mm, QFN, quatre FPC),
cuivre interne standard. La nomenclature d'assemblage (`jlc-bom.csv`,
`jlc-cpl.csv`) est complète en références, mais ses codes LCSC restent
à vérifier ligne par ligne avant tout ordre d'assemblage
([note 22](../../docs/notes/22-erreurs-de-conception.md), point 11).

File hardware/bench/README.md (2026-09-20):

# Banc Nucleo : shield d'alimentation et de liaison du quadrant 2 x 2

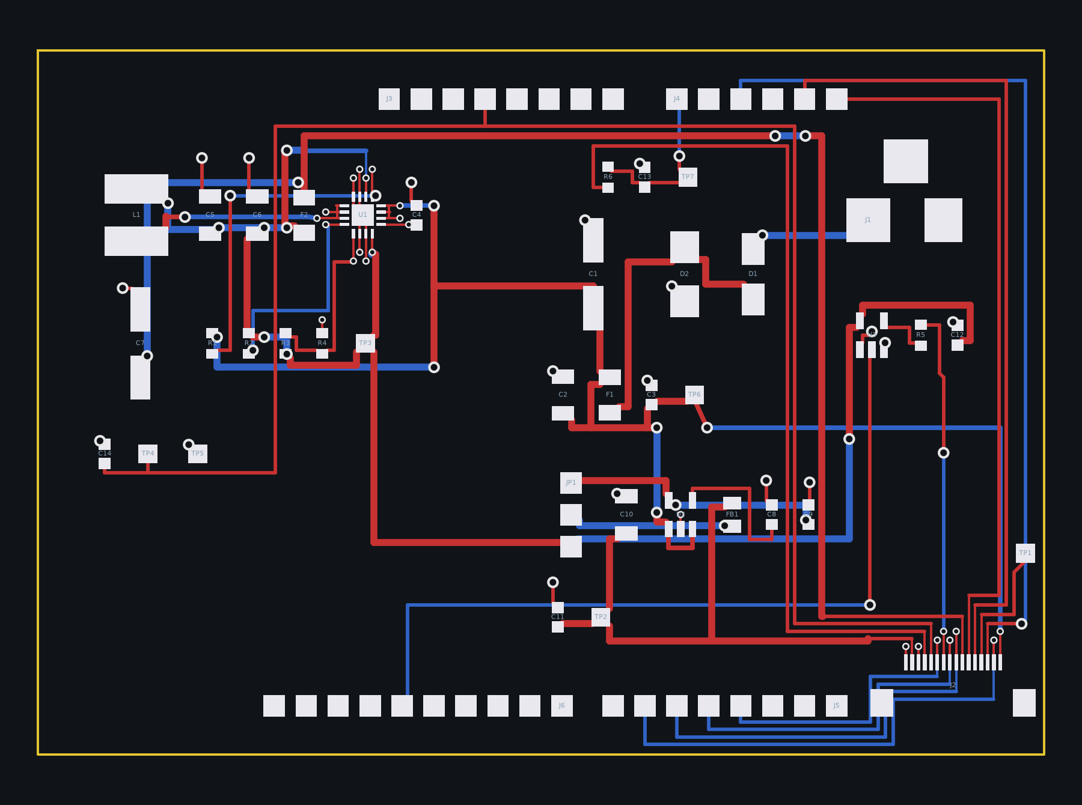
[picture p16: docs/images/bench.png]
Carte de banc


Les deux faces tracées par KiCad, pours remplis (`tools/plot.py`) :
la face composants avec sa sérigraphie, puis la face masse vue
retournée, comme on regarde la carte réelle.

Face composants

Face masse, vue retournée

Carte générée par `tools/boardgen` (module `bench`) depuis la section
`bench` de `config/board.yaml`, pour le banc de la
[note 19](../../docs/notes/19-cerveau-et-banc-nucleo.md) : une
Nucleo-G474RE (le MCU du cerveau, sa sonde et son port série) qui
mesure le quadrant réduit 2 x 2 (`hardware/quadrant-2x2/`) avec le
firmware du cerveau compilé en `make NUCLEO=1`. Le shield apporte au
quadrant ce que le cerveau lui aurait donné, et rien d'autre.
80 x 56 mm, 2 couches : composants et signaux sur F.Cu, plan de masse
sur B.Cu. Elle s'emboîte sur les quatre embases Arduino de la Nucleo
par des barrettes mâles montées côté cuivre, corps sous la carte.

## Blocs

- **Embases Arduino** (J3 alimentation, J4 analogique, J5 numérique 0 à
  7, J6 numérique 8 à 15) : positions prises sur l'empreinte officielle
  `Arduino_UNO_R3`, contour Uno affleurant au bord ouest, bande de
  11,4 mm à l'est pour le jack et la nappe. Le bus du quadrant est sur
  les broches de `bench.signals` : AMP_OUT (après RC) sur A0, PULSE_EN
  sur A2, MUX_A0 à A2 sur D3, D4, D5, MUX_EN_L sur A5, MUX_EN_H sur A4,
  DAMP_EN_N sur D6, LED_DIN sur D13. Le shield prend le 3,3 V et la
  masse de la Nucleo ; son 5 V ne remonte jamais vers elle (la Nucleo
  reste sur l'USB de sa sonde), VIN, 5V, IOREF, NRST et AREF restent
  ouverts.
- **Entrée 12 V** (J1 jack 5,5 x 2,1 mm, prise vers l'est) : SS34 en
  série contre l'inversion, SMBJ15A vers la masse, fusible 1 A, puis
  100 µF, 10 µF et 100 nF : la réserve du rail d'impulsion, comme sur
  le cerveau, dans la colonne centrale entre le jack et le buck.
- **Buck 5 V** (TPS62130, 2,2 µH, DEF haut : PWM forcé) : le rail des
  LED à travers un second fusible 2 A et 100 µF, et l'alimentation du
  tampon LED. Colonne ouest, là où le motif Uno laisse le shield vide.
- **Îlot analogique 5VA** : LP2985-5.0 depuis le 12 V, perle de
  ferrite BLM21PG221, 10 µF et 100 nF, comme sur le cerveau. Le
  cavalier JP1 choisit la source de 5VA_RAW : broches 1 et 2, le LDO
  (défaut) ; 2 et 3, le buck. C'est la comparaison LDO contre buck de la
  mesure M8.
- **Liaison quadrant** : J2, FPC 16 broches Hirose FH12 au brochage du
  quadrant (`plateau.quadrant.link.pinout`), au coin sud-est, nappe
  vers le sud, pastilles vers le nord ; tampon 74AHCT1G125 (3,3 V vers
  5 V) et 470 ohms devant LED_DIN, LED_DOUT sur un point de test ;
  49,9 ohms et 1 nF devant A0, le filtre du cerveau.
- **Points de test** : TP1 LED_END (au coin sud-est, contre le
  connecteur FPC), TP2 5VA, TP3 5V, TP4 3V3, TP5 GND, TP6 VIN, TP7 ADC1
  (AMP_OUT filtré). Le bus de commande (PULSE_EN, DAMP_EN_N, adresses
  du mux) se sonde sur les broches Morpho de la Nucleo, qui doublent
  chaque broche Arduino.

## Ce qui se soude à la main

Le tampon LED, le buck, l'inductance, le LDO, la perle, les diodes,
le jack et le connecteur FPC reprennent les références du cerveau,
code LCSC compris. Les passifs, les quatre barrettes Arduino (côté
cuivre), JP1 et les points de test n'ont pas de code : `jlc-bom.csv`
ne liste que les lignes qui en ont un, le reste se soude à la main ou
attend la passe de sourcing des autres cartes.

## Régénérer

```bash
PYTHONPATH=tools .venv/bin/python -m boardgen build bench --render docs/images/bench.png
/usr/bin/python3 tools/plot.py hardware/bench/bench.kicad_pcb --out docs/images
```

La seconde commande, avec le Python de KiCad, remplit les pours et
trace les deux faces en SVG (`bench-top.svg`, `bench-bottom.svg`).

`tests/test_bench.py` vérifie que chaque signal du bus est sur la
broche du cerveau (sauf DAMP_EN_N, déplacé de PC2 à D6 parce que PC2
n'atteint qu'un connecteur Morpho), que chaque broche d'embase porte
le net que dit le yaml, que la nappe reprend le brochage du quadrant,
et que chaque broche de barrette tombe sur la pastille de l'empreinte
Uno qu'elle représente.

## Routes manuelles

Le routeur seul laissait six nets ouverts et, au DRC de KiCad, une
trentaine de connexions manquantes que son propre bilan ne voyait pas
(couloirs de sortie des vias d'éventail sans cuivre, pistes finissant
sur le coin arrondi d'une pastille, voir la
[note 04](../../docs/notes/04-routeur-et-garanties.md)). La carte se
finit donc comme dans pcbnew, mais dans le générateur, par des routes
manuelles (`hand_routes` de `tools/boardgen/bench.py`) que chaque
build redessine et vérifie :

- **Éventail du FPC** (J2, seize pastilles au pas de 0,5 mm) : pas de
  via d'éventail dans le plan de masse ; chaque broche quitte son
  moignon sur une colonne de 0,2 mm et tourne à sa hauteur dans une
  voie de 0,3 mm, vers l'ouest pour 5VA, AMP_OUT1, 3V3 et 5V_LED, vers
  l'est pour MUX_EN_L, MUX_EN_H, LED_END et PULSE_EN, la broche la
  plus extérieure d'abord, la suivante une voie plus haut, si bien
  qu'aucune voie ne croise une colonne ; les fins de voies sont
  décalées pour laisser un via au bout de chacune. MUX_A0, MUX_A1,
  MUX_A2 et DAMP_EN_N prennent un petit via aux rangées d'éventail et
  passent en face arrière sous le connecteur, puis sous l'embase J5
  jusqu'à leurs broches ; VIN et LED_DIN1 de même vers le nord. Les
  deux broches de masse tombent au plan par un via au bout de leur
  piste d'envol.
- **Bande est** : MUX_EN_L monte en face avant jusqu'à la rangée de J4
  et entre dans la dernière broche par le bout de la rangée, MUX_EN_H
  passe au-dessus de la rangée, PULSE_EN monte en face arrière le long
  du bord (les deux se croiseraient sinon), LED_END rejoint TP1.
- **Face nord** : 3V3 monte à l'ouest de C9, passe sous les embases
  jusqu'à J3, continue vers l'ouest et redescend entre C6 et R3 vers
  TP4 et C14 ; 5V_LED et AMP_OUT1 suivent, une voie plus bas chacune,
  jusqu'au fusible des LED et au filtre de l'ADC, 5V_LED sautant en
  face arrière sur deux millimètres pour franchir la montée de 3V3 ;
  VIN traverse la carte en face arrière à mi-hauteur jusqu'à TP6.
- **Buck** : une barrette de 0,2 mm sur les bouts de moignons relie
  les trois pastilles SW, une autre les trois VIN (le routeur posait
  une piste de puissance le long d'une piste d'envol, à 0,10 mm du
  moignon voisin) ; SW part en face arrière vers l'inductance, VIN vers
  un via à l'est de C4 puis le condensateur d'entrée, la pastille 5 V
  du côté nord suit son couloir de sortie ; les quatre pastilles de
  masse du QFN sont pontées à son pad thermique.
- **Masses murées** : la pastille de masse du LDO (entre ses deux
  VIN) et celle de R4 ont un moignon et un petit via vers le plan.

Chaque route manuelle est vérifiée au build par le contrôle
d'isolement exact contre le cuivre déjà posé ; le routeur part de ces
routes et termine chaque net. Un déplacement de composant qui les
rendrait fausses fait échouer le build.

## Résultat du build

Généré par `python -m boardgen build bench` :

| Composants | Segments | Vias | Nets fermés | Nets ouverts | Défauts d'isolement |
|---|---|---|---|---|---|
| 43 | 263 | 72 | 29 | 0 | 0 |

Tous les nets sont fermés : le contrôle de connexité partagé des
générateurs (`tools/quadgen/connect.py`, chaque net une seule pièce de
cuivre, plan de masse compris, [note 04](../../docs/notes/04-routeur-et-garanties.md))
ne signale rien, `tests/test_bench.py` le vérifie à chaque exécution.

DRC KiCad 7.0.11 (`/usr/bin/python3 tools/drc.py
hardware/bench/bench.kicad_pcb`, zones remplies) : zéro erreur, zéro
élément non connecté ; 83 avertissements, tous ignorables : 43
chemins de bibliothèque des empreintes (la configuration de KiCad ne
connaît pas les bibliothèques par leur nom), 35 de sérigraphie
(références sur une ligne ou une pastille), 5 vias d'éventail du QFN
raccordés d'un seul côté (la route est partie en face avant).

## Gerbers de fabrication

`bench-gerbers.zip` se dépose tel quel chez le fabricant : 2 couches
(F.Cu, B.Cu), la pâte de la face composants, les deux sérigraphies,
les deux masques, le contour et les perçages Excellon séparés (PTH et
NPTH), plus le fichier de tâche `.gbrjob`. 1,6 mm, finition HASL sans
plomb ou ENIG ; les options de commande et la nomenclature sont dans
la [note 20](../../docs/notes/20-tuto-banc.md), section 3.

À côté de l'archive, `<carte>-gerbers.sha256` porte l'empreinte de la
carte tracée et celle de l'archive. À vérifier avant toute commande :

```bash
cd hardware/bench && sha256sum -c bench-gerbers.sha256
```

Options écran par écran, quantités et décisions à trancher : la
[note 23](../../docs/notes/23-commande-jlcpcb.md).

```bash
/usr/bin/python3 tools/gerbers.py hardware/bench/bench.kicad_pcb
```

Avec le Python de KiCad : l'outil remplit les pours d'une copie de la
carte avant de tracer (sans ce remplissage le plan de masse de B.Cu
sort vide), lit le jeu de couches sur la carte, et refuse d'exporter
tant qu'une pastille reste non connectée. Le dossier `gerbers/` qu'il
écrit n'est pas versionné ; l'archive l'est.

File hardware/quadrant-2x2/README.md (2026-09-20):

# Quadrant réduit 2 x 2 : banc de mise au point du quadrant

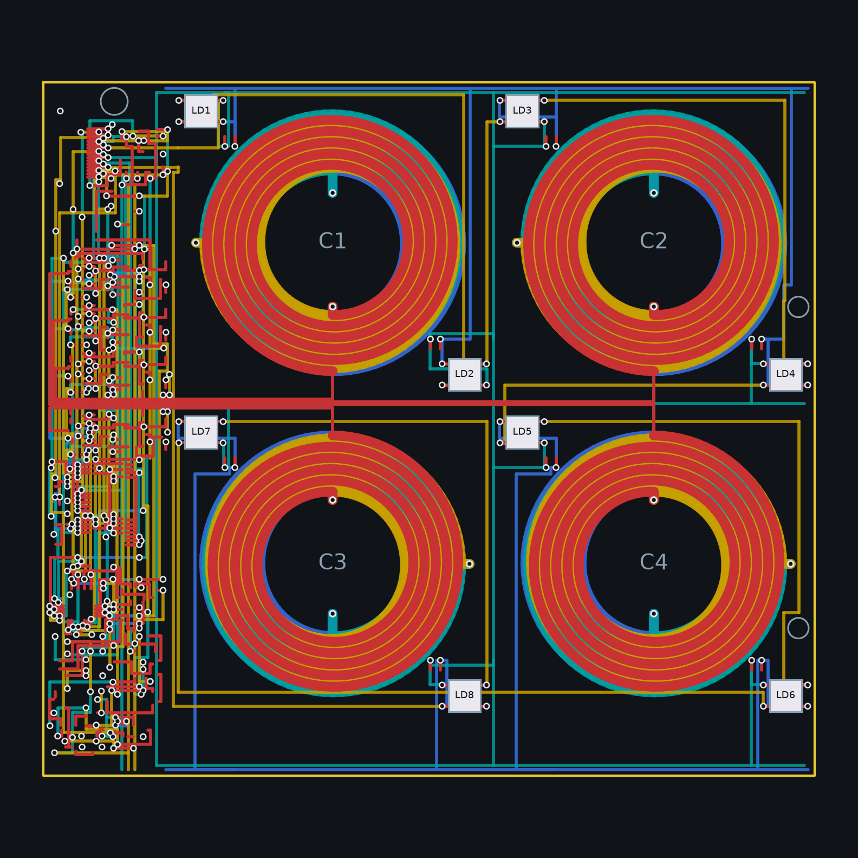
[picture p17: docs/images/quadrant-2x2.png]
Quadrant 2 x 2


Carte générée par `tools/quadgen` avec l'option `--reduced`, depuis
`config/board.yaml` (`plateau.quadrant.reduced`) : le même circuit, le
même bus de commande et le même firmware que le quadrant 4 x 4
([README](../quadrant/README.md)), avec quatre cases au lieu de seize.
Elle sert à valider le schéma, le frontal et la mesure sur une carte
courte et bon marché avant de commander les quadrants du plateau. La
fonction, les composants et leur câblage sont décrits bloc par bloc
dans la [note 17](../../docs/notes/17-quadrant-fonction-et-cablage.md).

## Ce que contient la carte

- 120 x 108 mm, 4 couches : 20 mm de bande de frontal à l'ouest
  (`plateau.quadrant.front_end_strip_mm`), deux colonnes de cases de
  50 mm, et un dépassement de 8 mm au sud (`reduced.strip_overhang_mm`)
  parce que la bande de frontal, avec une seule bande d'échappée et ses
  quatre cellules, est plus longue que deux cases.
- 4 spirales de détection identiques à celles du 4 x 4 (4 couches en
  série, 5 tours par couche, piste 1,6 mm), bornes au sud de la rangée
  0 et au nord de la rangée 1, échappées dans la bande qui les sépare
  vers les cellules du frontal, borne A sur F.Cu et borne B sur B.Cu.
- 8 WS2812B aux coins NO et SE de chaque case, un 100 nF chacune,
  chaîne de données en serpentin sur In1, grille 5 V sur In2, masse
  sur B.Cu le long des bords nord et sud (pas de couloir médian : dans
  un 2 x 2 le seul couloir est la bande d'échappée). La chaîne ne
  traverse jamais le frontal : elle entre et sort par deux voies
  dessinées au connecteur, une par sens.
- Masse du frontal : un plan sur B.Cu sous toute la bande, à la place
  de l'ancien bus sur In1. Les échappées des bobines le coupent en
  deux, quelques routes de la couche arrière y ouvrent des criques ;
  le build calcule les îlots réellement remplis et les fait recoudre
  ([note 04](../../docs/notes/04-routeur-et-garanties.md)).
- Connecteur FPC 16 broches 0,5 mm (Hirose FH12), brochage dans
  `plateau.quadrant.link.pinout`, identique au 4 x 4 : le cerveau ne
  voit pas la différence, `COILS_PER_QUADRANT` vaut 4 dans son firmware
  de test.
- Trou de pion de centrage en bas de la bande, deux trous de fixation
  M3 au bord est.

## Le frontal de la bande

Le même que sur le 4 x 4, avec les deux points de la note 17 intégrés :

- 4 cellules de 7,4 mm en face de leur bobine : polarisation 10 k vers
  VREF, 330 ohms et BAV99W (SOT-323) devant le mux, diode de bus B5819W
  et AO3400A d'excitation, SS34FL de roue libre vers VIN, **B5819W de
  roue libre depuis la masse** (le courant de la bobine se referme par
  elle quand le N-FET s'ouvre, quel que soit l'état du commutateur de
  rail), AO3401A et 680 ohms d'amortissement pilotés directement par
  le décodeur (plus de rappel vers VIN). Résistances de polarisation et
  d'écrêtage en 0603, amortissement en 0805, rappel de grille en 0402.
- Décodeurs 74HC4514 (excitation, inhibé par PULSE_EN à travers un
  74LVC1G04) et 74HC154 (amortissement, validé par DAMP_EN_N), sorties
  4 à 15 laissées libres ; un seul ADG1607 (bobines 1 à 4, enable
  MUX_EN_L) ; AD8421 G = 20, deux Sallen-Key OPA2810, tampon VREF et
  étage de sortie, écrêtage vers 3V3 et RC de sortie.
- Commutateur de rail d'impulsion AO3401A commandé par un AO3400A,
  **R7 de 470 ohms** pour que le rail se coupe en moins d'une
  microseconde après PULSE_EN, avant la fenêtre d'écoute ; 10 ohms
  2010 vers le bus des cellules.

## Le schéma

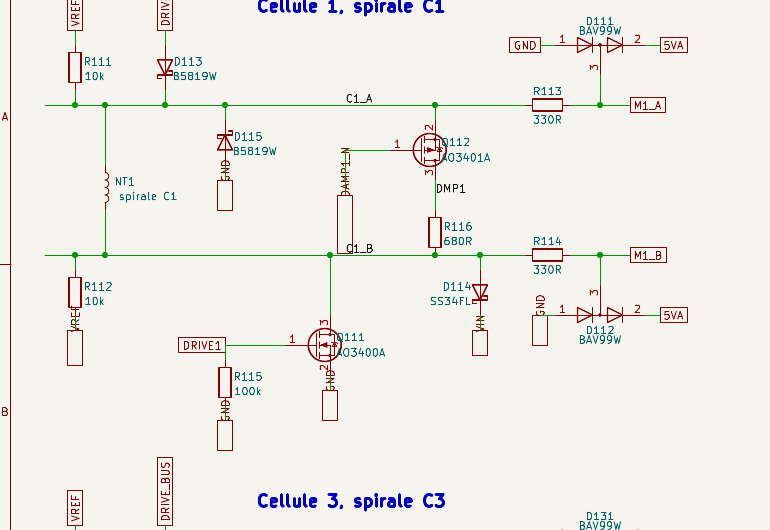
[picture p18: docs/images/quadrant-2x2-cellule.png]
Cellule de bobine, feuille cells-1


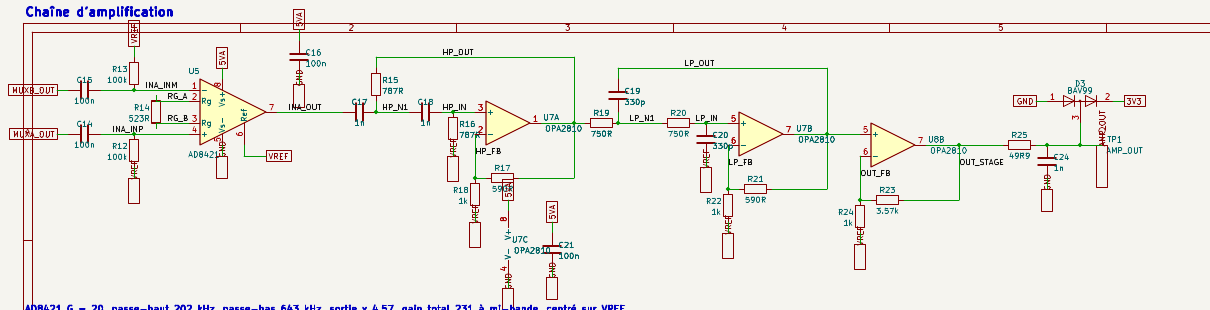
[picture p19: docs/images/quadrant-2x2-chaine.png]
Chaîne d'amplification, feuille chain


`quadrant-2x2.kicad_sch` est la feuille racine (connecteur J1 et les
blocs) ; les feuilles `rails`, `cells-1`, `select`, `chain` et `leds`
dessinent chaque bloc avec ses fils, une étiquette globale pour les
rails, le bus d'adresse et les nets partagés entre feuilles, une
étiquette locale pour les nets internes. Le dessin est vérifié contre
le circuit à chaque build et la netlist relue par `kicad-cli` est
comparée au circuit en test (`tests/test_drawn_schematic.py`).

Sorties du build : projet KiCad avec ses six feuilles, `bom.csv`,
`jlc-bom.csv` (lignes avec code LCSC), `jlc-cpl.csv`, `chain-spice.cir`.

## Résultat du build

Généré par `python -m quadgen build --reduced` (18/09/2026) :

| Bobines | LED | Segments | Vias | Nets ouverts | Pastilles ouvertes | Défauts d'isolement |
|---|---|---|---|---|---|---|
| 4 | 8 | 8706 | 371 | 0 | 0 | 0 |

DRC KiCad 7 (`tools/drc.py`, zones remplies) : 395 signalements,
**zéro erreur et zéro élément non connecté**, contre 117 éléments non
connectés le matin du même jour et sept après le reroutage. Le compte du
build et celui de KiCad disent la même chose, c'est ce que permet la
comptabilité de connexité partagée de la
[note 04](../../docs/notes/04-routeur-et-garanties.md). Avertissements
sans effet sur la fabrication : silk_overlap 151, lib_footprint_issues
129, silk_over_copper 75, track_dangling 25, via_dangling 11,
silk_edge_clearance 4. Le contrôle d'isolement exact du générateur ne
signale aucun défaut.

Les sept dernières liaisons ne relevaient pas du routeur mais de la
géométrie : un chas de 0,475 mm dans le champ d'échappées du connecteur
là où une piste avec ses gardes demande 0,55, deux nappes longues comme
la bande, quatre pastilles de la colonne d'amplification que les deux
rails analogiques enjambent sans laisser la place d'un via, et une
crique du plan de masse. Elles sont tracées dans
`tools/quadgen/hand.py`, avant le routage comme les prises des
cellules, donc le build les redessine et les vérifie à chaque fois, et
le routeur route le reste autour d'elles. Le détail de chacune est dans
la [note 04](../../docs/notes/04-routeur-et-garanties.md).

Deux garde-fous encadrent ces tracés :
`tests/test_quadgen.py::test_reduced_strip_geometry_is_legal_before_routing`
redessine tout le cuivre posé avant le routage et lui applique le
contrôle d'isolement exact en cinq secondes, et le build complet
échoue s'il reste une liaison ouverte.

## Régénérer

```bash
PYTHONPATH=tools .venv/bin/python -m quadgen build --reduced --render docs/images/quadrant-2x2.png
/usr/bin/python3 tools/plot.py hardware/quadrant-2x2/quadrant-2x2.kicad_pcb --out docs/images
/usr/bin/python3 tools/drc.py hardware/quadrant-2x2/quadrant-2x2.kicad_pcb
```

La deuxième commande, avec le Python de KiCad, remplit les pours et
trace les deux faces en SVG ; la troisième compte les éléments non
connectés, qui doivent tomber à zéro avant toute commande.

Face composants

Face masse, vue retournée

## Gerbers de fabrication

`quadrant-2x2-gerbers.zip` se dépose tel quel chez le fabricant :
4 couches (F.Cu, In1.Cu, In2.Cu, B.Cu), la pâte de la face
composants, les deux sérigraphies, les deux masques, le contour et les
perçages Excellon séparés (PTH et NPTH), plus le fichier de tâche
`.gbrjob`. 1,6 mm ; les vias d'éventail de 0,45 mm à perçage 0,2 mm
sous les boîtiers fins passent dans le procédé standard de JLCPCB en
quatre couches (minimum annoncé 0,25 mm de diamètre pour 0,15 mm de
perçage), donc sans option ni surcoût, et un pochoir rend la pose du
frontal beaucoup plus sûre. Options de commande et nomenclature dans la
[note 20](../../docs/notes/20-tuto-banc.md), section 3.

À côté de l'archive, `<carte>-gerbers.sha256` porte l'empreinte de la
carte tracée et celle de l'archive. À vérifier avant toute commande :

```bash
cd hardware/quadrant-2x2 && sha256sum -c quadrant-2x2-gerbers.sha256
```

Options écran par écran, quantités et décisions à trancher : la
[note 23](../../docs/notes/23-commande-jlcpcb.md).

```bash
/usr/bin/python3 tools/gerbers.py hardware/quadrant-2x2/quadrant-2x2.kicad_pcb
```

Avec le Python de KiCad : l'outil remplit les pours d'une copie de la
carte avant de tracer (sans ce remplissage le plan de masse de la
bande sort vide), lit le jeu de couches sur la carte, et refuse
d'exporter tant qu'une pastille reste non connectée. Le dossier
`gerbers/` qu'il écrit n'est pas versionné ; l'archive l'est.

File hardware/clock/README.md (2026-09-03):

# Horloge à bascule : carte

Carte horloge

Générée par `tools/boardgen` (module `clock`). 110 x 60 mm, 2 couches,
dans le boîtier de `mechanical/clock.py`.

- **Radio et calcul** : module ESP32-S3-WROOM-1 (le même que sur le
  cerveau, BLE vers le plateau), antenne hors du bord est, cour réduite
  à la largeur du module (l'encodeur et un microrupteur sont de part et
  d'autre, choix assumé pour du BLE à courte portée), boutons BOOT et
  EN, embase de programmation 1 x 6, diviseur de tension batterie sur
  IO1, état du chargeur sur IO2 par un diviseur 56 k / 100 k (STAT monte
  à 5 V).
- **Énergie** : USB-C en alimentation seule (5,1 k sur CC, D+, D- et SBU
  non connectés), chargeur 1S MCP73831 à 500 mA avec LED d'état,
  support 18650 Keystone 1042, embase pour l'interrupteur, AP2112K 3,3 V.
- **Interface** : embase 1 x 14 pour un écran 2,4 pouces ILI9341 SPI
  avec tactile, rétroéclairage commuté par un P-FET AO3401A sur 3V3
  (IO7 actif bas, éteint au démarrage), deux microrupteurs 6 x 6 sous
  les extrémités de la
  barre à bascule (positions dérivées de `clock.rocker` du yaml, la
  carte étant à 5 mm des parois du boîtier), encodeur EC11 à poussoir
  à l'avant droit sous son trou de la face inclinée, buzzer 12 mm sur
  transistor, USB-C dans la fente arrière.

```bash
PYTHONPATH=tools .venv/bin/python -m boardgen build clock --render docs/images/clock.png
```

## Résultat du build

Généré par `python -m boardgen build clock` :

| Composants | Segments | Vias | Nets fermés | Nets ouverts | Défauts d'isolement |
|---|---|---|---|---|---|
| 50 | 307 | 149 | 31 | 6 | 0 |

Nets à finir dans pcbnew (le routeur les a laissés ouverts) :
- CHG_SENSE: 1 pad(s) left open (usable start cells 77, goal cells 85)
- CC2: 2 pad(s) left open (usable start cells 8, goal cells 50)
- GND: pad at cell (131, 39) has no drop to the pour
- GND: pad at cell (149, 30) has no drop to the pour
- GND: pad at cell (464, 98) has no drop to the pour
- GND: pad at cell (542, 102) has no drop to the pour

DRC KiCad 7 (`tools/drc.py`, zones remplies) : 178 signalements, 51 éléments non connectés (les nets ouverts ci-dessus), erreurs restantes : aucune ; avertissements sans effet sur la fabrication : via_dangling 53, lib_footprint_issues 50, silk_overlap 38, track_dangling 28, silk_over_copper 8, silk_edge_clearance 1. Le contrôle d'isolement exact du générateur ne signale aucun défaut. Les vias d'éventail des boîtiers fins font 0,45 mm (perçage 0,2 mm), dans les capacités standard de JLCPCB, à confirmer sur le devis.

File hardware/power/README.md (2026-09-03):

# Carte puissance : pack 3S, charge, protection, jauge

Carte puissance

Générée par `tools/boardgen` (module `power`). 100 x 60 mm, 2 couches,
plan de masse en face arrière. Elle gère trois cellules plates 1S 5 Ah.

- **Entrée** : 20 V depuis un module déclencheur USB-C PD du commerce
  (connecteur JST XH 2 broches), TVS SMBJ24A, sens de courant d'entrée
  10 mohms, deux P-FET AO3401A dos à dos (drain commun) que la sortie
  ACDRV, active bas, pilote.
- **Chargeur** : BQ24610, buck synchrone à deux AO3400A, self 10 µH,
  sens de courant 50 mohms (1 A = 50 mV), régulation 12,6 V par
  diviseur sur VFB, courant de charge 1 A (ISET1 à 0,995 V), précharge
  et fin de charge 0,2 A (ISET2 à 0,101 V), limite d'entrée 2,5 A
  (ACSET à 0,499 V), fenêtre de température 0 à 45 °C par le réseau
  5,23 k / 30,1 k de la fiche sur une CTN 10 k, sorties STAT et PG
  tirées au 3,3 V de l'AFE. Pas de chemin d'alimentation : le système
  tourne sur le pack, BATDRV reste libre.
- **Protection** : BQ76920 (AFE 3 à 5S) avec ses filtres 1 k / 100 nF
  par cellule, deux FET AO3400A en bas côté dans le retour du pack (DSG
  source côté cellules après la résistance de mesure, CHG source sur
  PACK-), sens 5 mohms, CTN, I2C vers le cerveau, sortie ALERT.
- **Jauge** : INA219 sur un shunt 10 mohms côté haut, même bus I2C.
- **Sorties** : fusible 2 A, embase pour un interrupteur, bouton de
  réveil (PWR_KEY), liaison 2 x 4 vers le cerveau, connecteur cellules
  JST XH 4 broches (B-, B1, B2, B+).

Les valeurs d'ISET, d'ACSET et du diviseur de tension suivent
l'application type du BQ24610, revues dans la
[note 14](../../docs/notes/14-revue-des-cartes.md) ; les formules
(ICHG = V(ISET1) / 20 RSR, IPRE = ITERM = V(ISET2) / 10 RSR) et la
plage admise de V(ISET2) restent à confirmer sur la fiche. Points
ouverts : la CTN de charge est sur la carte alors que le yaml la veut
sur le pack (deux broches de plus au connecteur cellules), et le cerveau
ne doit jamais ouvrir DSG par I2C (rien ne le refermerait).

```bash
PYTHONPATH=tools .venv/bin/python -m boardgen build power --render docs/images/power.png
```

## Résultat du build

Généré par `python -m boardgen build power` :

| Composants | Segments | Vias | Nets fermés | Nets ouverts | Défauts d'isolement |
|---|---|---|---|---|---|
| 82 | 429 | 158 | 42 | 10 | 0 |

Nets à finir dans pcbnew (le routeur les a laissés ouverts) :
- REGN: 2 pad(s) left open (usable start cells 28, goal cells 72)
- TS1: 2 pad(s) left open (usable start cells 43, goal cells 63)
- SCL: 4 pad(s) left open (usable start cells 34, goal cells 314)
- SDA: 4 pad(s) left open (usable start cells 34, goal cells 318)
- 3V3_BMS: 1 pad(s) left open (usable start cells 534, goal cells 34)
- SRN: 1 pad(s) left open (usable start cells 163, goal cells 84)
- SRP: 1 pad(s) left open (usable start cells 642, goal cells 84)
- CELL3: 6 pad(s) left open (usable start cells 30, goal cells 483)
- PACK+: 1 pad(s) left open (usable start cells 313, goal cells 100)
- BAT-: 16 pad(s) left open (usable start cells 39, goal cells 969)

DRC KiCad 7 (`tools/drc.py`, zones remplies) : 307 signalements, 69 éléments non connectés (les nets ouverts ci-dessus), erreurs restantes : aucune ; avertissements sans effet sur la fabrication : silk_overlap 121, lib_footprint_issues 82, via_dangling 56, silk_over_copper 36, track_dangling 12. Le contrôle d'isolement exact du générateur ne signale aucun défaut. Les vias d'éventail des boîtiers fins font 0,45 mm (perçage 0,2 mm), dans les capacités standard de JLCPCB, à confirmer sur le devis.

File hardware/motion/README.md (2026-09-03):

# Carte moteurs : option chariot

Carte moteurs

Générée par `tools/boardgen` (module `motion`). 90 x 60 mm, 2 couches.
Elle vit dans la base chariot et se branche au cerveau par la nappe
IDC 2 x 10.

- Deux embases pour modules TMC2209 SilentStepStick (brochage Pololu :
  EN, MS1, MS2, PDN_UART x 2, CLK, STEP, DIR ; VM, GND, 2B, 2A, 1A, 1B,
  VIO, GND), adresses UART 0 et 1 par MS1, un seul fil UART à travers
  1 k, réserve 100 µF par pilote.
- Moteurs sur JST XH 4 broches, fins de course X et Y sur JST XH 3
  broches (GND, 3,3 V, signal), servo de l'actionneur d'aimant sur
  JST XH 3 broches (signal, 5 V, GND).
- Points de test, quatre trous M3.

```bash
PYTHONPATH=tools .venv/bin/python -m boardgen build motion --render docs/images/motion.png
```

## Résultat du build

Généré par `python -m boardgen build motion` :

| Composants | Segments | Vias | Nets fermés | Nets ouverts | Défauts d'isolement |
|---|---|---|---|---|---|
| 31 | 151 | 109 | 27 | 1 | 0 |

Nets à finir dans pcbnew (le routeur les a laissés ouverts) :
- MOT_DIAG

Le contrôle d'isolement exact ne signale aucun défaut : ce qui est
tracé respecte les règles, ce qui manque est listé ci-dessus. Les vias
d'éventail des boîtiers fins font 0,45 mm (perçage 0,2 mm), à
confirmer avec le fabricant avant commande.

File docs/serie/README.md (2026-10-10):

# Série vidéo « Échec et Watt » : la bible

Documenter la construction de l'échiquier en épisodes courts verticaux
(TikTok, Reels, Shorts), tournés au fil du projet avec Romain, et
offerts à Ayglon avec le plateau, à Noël (son anniversaire, le 1er
octobre, est une étape en chemin). Ce
dossier est la bible de la série : concept, format, direction
artistique, organisation, règles de publication. Le découpage et les
scripts sont dans [episodes.md](episodes.md), la méthode de tournage
dans [tournage.md](tournage.md), le montage dans
[montage.md](montage.md).

Rien de ce dossier ne fait autorité sur la technique : les chiffres
cités dans les scripts viennent de `config/board.yaml` et des notes
de `docs/notes/`, et sont à relire avant chaque tournage.

## Le concept en une phrase

Deux amis construisent, de zéro, un échiquier qui reconnaît les
pièces et les déplace tout seul, pour l'offrir à un troisième qui ne
doit rien savoir. Le spectateur suit les étapes, les ratés et la
mesure qui peut tout faire tomber, jusqu'à la remise du cadeau.

Deux fils narratifs se croisent :

- **Le fil technique** : une idée par épisode, expliquée avec un objet
  dans la main, jamais avec un schéma seul.
- **Le fil humain** : le secret, le compte à rebours jusqu'à
  la remise, la complicité avec Romain, et la réaction finale
  d'Ayglon comme dernier épisode.

## Titre et identité

Titre recommandé : **Échec et Watt**. Deux variantes en réserve :
« Cavalier seul » (le plateau joue sans main) et « Roque and roll ».
Le titre apparaît en carton d'ouverture 0,5 s maximum, puis en petit
dans le coin haut gauche.

Signature sonore : chaque pièce du projet est un résonateur accordé
entre 217 et 613 kHz. Ramenées mille fois plus bas, ces fréquences
tombent dans l'audible (217 à 613 Hz, du la 3 au ré dièse 5) : **chaque
pièce a sa note**. La série s'ouvre et se ferme sur cette gamme de
douze notes jouée en ringdown (attaque nette, extinction douce), et
chaque identification de pièce à l'écran est ponctuée de « sa » note.
Le son est à synthétiser depuis les fréquences calculées par
`chessboard_calc` (proposition d'outil dans [montage.md](montage.md)).

## Le format

| Paramètre | Choix |
|---|---|
| Cadre | vertical 9:16, 1080 x 1920 |
| Cadence | 30 i/s, 60 i/s pour les ralentis (aimants, pièces qui bougent) |
| Durée | 45 à 75 s ; le teaser et les épisodes pivot peuvent aller à 90 s |
| Structure | accroche (0 à 2 s), contexte (une phrase), le geste, le résultat ou le raté, la relance |
| Voix | voix off enregistrée après tournage, plus quelques prises face caméra pour les moments forts |
| Sous-titres | incrustés, toujours (la majorité regarde sans le son) |
| Rythme | un plan toutes les 2 à 4 s, jamais plus de 6 s sans changement |
| Langue | français, tutoiement, phrases courtes, aucun jargon sans image qui l'explique |

Une règle d'or : **un épisode, une idée**. Si un tournage produit deux
idées, il produit deux épisodes.

## Les rubriques récurrentes

Elles donnent un rythme reconnaissable et facilitent l'écriture.

- **Le chiffre** : un nombre du projet plein écran, en police mono,
  avec sa phrase d'explication (exemple : « 12 : le nombre de notes,
  donc de types de pièces à reconnaître »). Une fois par épisode.
- **La décision** : quand un épisode repose sur un ADR, un carton
  « Décision 0002 : ferrite, jamais néodyme » avec la raison en une
  ligne. Cela relie la série au dépôt sans le montrer.
- **Le raté** : ce qui n'a pas marché, montré sans détour. C'est la
  rubrique qui fait revenir les gens.
- **Le compte à rebours** : « J moins N » avant la remise, en
  petit dans le coin bas droit, tenu à jour à chaque épisode.
- **Le plateau de progression** : un échiquier 8 x 8 stylisé où chaque
  épisode publié allume une case. Il ferme chaque épisode (1 s) et
  montre d'un coup d'œil où en est la série.

## Direction artistique

Le projet a déjà une esthétique : bois, cuivre des spirales, noir et
blanc des cases, points lumineux de camp. La série la reprend.

### Palette

| Rôle | Couleur | Usage |
|---|---|---|
| Fond | bois clair (#D9B98C) ou plan réel de contreplaqué | cartons, fond des chiffres |
| Encre | noir profond (#141414) | texte principal, cases noires |
| Cuivre | #B87333 | accents, soulignements, spirales à l'écran |
| Camp blanc | blanc chaud (#F4EFE6) | LED de camp blanc, cases blanches |
| Camp noir | ambre (#FFB347) | LED de camp noir, alertes, « le raté » |
| Signal | cyan (#2EC4B6) | courbes, ringdown, tout ce qui vient de la mesure |

Deux couleurs maximum par écran en plus du noir et du blanc.

### Typographie

- Titres et cartons : une grotesque grasse et large (Inter Black,
  Archivo Black ou équivalent), majuscules, interlettrage serré.
- Chiffres et données : une mono (JetBrains Mono, IBM Plex Mono).
  Tout ce qui vient d'une mesure est en mono, systématiquement.
- Sous-titres : la même grotesque en Bold, blanc avec contour noir de
  4 px, 2 lignes maximum, centrées dans le tiers inférieur, jamais
  sur les zones couvertes par l'interface de l'application (les 250
  px du bas et les 100 px du haut).

### Image

- Lumière : lumière du jour de côté ou une lampe unique en diagonale,
  jamais de plafonnier seul. Les plans macro (spirales, soudures,
  bobinage) avec une lampe rasante pour faire ressortir le relief.
- Cadres récurrents : plan de travail vu du dessus (trépied ou bras
  au-dessus de la table), macro à 10 cm, plan « épaule » sur celui
  qui fait le geste, plan large des deux à la fin.
- Mains à l'écran : toujours propres, manches relevées, une seule
  action par plan.
- Écrans : les captures (KiCad, terminal, notebook) sont recadrées en
  vertical et zoomées sur la zone utile, fond sombre, police à 2x.
  Jamais un écran entier filmé au téléphone.
- Ralenti : réservé aux aimants, aux pièces qui se déplacent et aux
  LED qui s'allument.

### Grammaire de montage

- Coupe franche partout. Un seul type de transition autorisé en plus :
  le « match cut » sur un objet (la pièce dessinée devient la pièce
  imprimée).
- Texte à l'écran : un mot clé par plan au maximum, pop simple, pas
  d'animation typographique complexe.
- Le ringdown (courbe qui s'éteint) est le motif visuel de la série :
  il sert d'intertitre, de barre de progression et de fermeture.

## Organisation à deux

Le principe : sur chaque étape, l'un mène et l'autre est en support ;
**celui qui est en support tient la caméra et monte l'épisode**. Le
meneur commente son geste à l'écran et enregistre la voix off, parce
qu'il sait ce qu'il vient de faire.

| Étape | Mène (à l'écran, voix off) | Support (caméra, montage) |
|---|---|---|
| Conception électronique, cartes, commande (E01 à E04) | Étienne | Romain |
| Impression, bobinage, bois (E05, E06, E08) | Romain | Étienne |
| Colis, câblage, firmware, mesures (E07, E09 à E13) | Étienne | Romain |
| Plateau 8 x 8, électronique (saison 2) | Étienne | Romain |
| Portique CoreXY, mécanique, ébénisterie (E19 à E22, E26, E27) | Romain | Étienne |
| Firmware de jeu, Pi, batterie (E23 à E25) | Étienne | Romain |
| Test final et remise (E28 à E30) | les deux | un troisième téléphone si possible |

Script : Étienne, relu par Romain, à partir de
[episodes.md](episodes.md). Face caméra : les deux, chacun tient la
caméra pour l'autre.

Rituel de tournage : avant chaque séance, relire la fiche de
l'épisode (accroche, plans obligatoires, chiffre, raté). Après la
séance, dix minutes pour renommer les rushes et noter dans le
journal de [tournage.md](tournage.md) ce qui manque.

## Publication : en différé, épisode par épisode

Choix retenu : rien n'est publié avant la remise du cadeau. Les
épisodes sont montés au fil du projet (au plus tard une semaine après
le tournage, sinon la mémoire des rushes s'efface), puis sortent
après la remise, **un par jour**, dans l'ordre, la réaction d'Ayglon
en avant-dernier et l'épilogue en dernier.

Conséquences pratiques :

- Le compte à rebours reste filmé en direct : il compte les jours
  jusqu'à la date de remise réelle, et c'est ce qui donne de la
  tension à la série même vue après coup.
- Le secret est narratif : jusqu'à E29, le destinataire s'appelle
  « notre pote » à l'écran, pour que la révélation garde son effet.
- Avant publication : accord d'Ayglon pour son image (E29, E30), et
  relecture de tous les épisodes déjà montés d'une traite pour
  vérifier la cohérence du compte à rebours et du plateau de
  progression.
- Pendant le projet, un compte n'est pas nécessaire ; les proches
  peuvent voir les exports en avant-première par un dossier partagé.

Musique : les bibliothèques intégrées de TikTok et Instagram ne sont
licenciées que dans l'application. Pour pouvoir cross-poster et
garder les fichiers, préférer des sons libres (voir
[montage.md](montage.md)) et la signature sonore maison.

## Calendrier

Deux dates : l'anniversaire d'Ayglon le **1er octobre 2026**, et le
repli **Noël 2026**. Point de départ : le 2 septembre, avec la
maquette conçue mais rien de physique.

### Ce qu'un mois permet, et ce qu'il ne permet pas

Le plateau complet (64 cases, portique, jeu) n'est pas atteignable
pour le 1er octobre : les cartes de la phase 2 ne sont pas conçues,
et une commande en Asie prend 2 à 5 semaines à elle seule. La
maquette 2 x 2, elle, peut fonctionner pour le 1er octobre à une
condition : commander les cartes **cette semaine** (finition pcbnew
et correction du jack J1 comprises), en livraison express, et faire
tout le reste (impression, bobinage, bois, câblage) pendant
l'attente.

Plan retenu : **la remise du plateau se fait à Noël**. Le 1er
octobre devient une étape de la série, avec deux variantes à choisir
selon l'état de la maquette la dernière semaine de septembre :

- **La promesse** : si la maquette reconnaît les quatre pièces, on
  offre à Ayglon une pièce d'échecs équipée de son résonateur et une
  carte : « ton cadeau est en construction, il sera prêt à Noël ».
  La maquette qui joue sa note sous ses yeux fait un épisode fort au
  milieu de la série (E13bis) ; le secret change de nature : il sait
  qu'il y a un cadeau, pas ce que c'est.
- **Le silence** : la maquette n'est pas prête, on offre autre chose,
  le secret reste entier jusqu'à Noël. La série n'en parle pas.

### Rétro-planning vers Noël

Il n'y a **aucune marge pour une deuxième commande** de cartes :
celles du plateau 8 x 8 doivent partir à la mi-octobre pour arriver
mi-novembre, ce qui impose de concevoir la phase 2 en septembre,
pendant l'attente des cartes de la maquette, et non après les
mesures. Les mesures de la maquette ne feront que confirmer ou
corriger cette conception (le pas de case surtout : concevoir en
paramétrique, choisir p à la commande).

| Semaine | Projet | Épisodes à tourner |
|---|---|---|
| 2 au 8 septembre | finition pcbnew (7 nets, jack J1), export, 4 commandes en express, impression des pièces | E01, E02, E03, E04, E05 |
| 9 au 22 septembre | bobinage (5 bobines), contreplaqué percé, feutre, câblage préparé ; conception du plateau 8 x 8 (quadrants, mux, chaîne LED) | E06, E08, rafale du teaser |
| 23 au 30 septembre | réception (si express), bring-up, M1 à M5 au minimum, M2 en priorité | E07, E09, E10, E11, E12 |
| 1er octobre | anniversaire : la promesse ou le silence | E13bis (si promesse) |
| 2 au 12 octobre | M6 à M11, tableau de synthèse, choix de p, ADR ; gel de la conception 8 x 8 | E13, E14 |
| 13 au 19 octobre | commande des quadrants 8 x 8 et de leur électronique ; début du CoreXY (conception, impression) ; bobinage de 32 résonateurs commencé | E16 (début), E19 (conception) |
| 20 octobre au 16 novembre | attente des cartes : CoreXY imprimé et assemblé à vide, firmware 8 x 8 et arbitre écrits sur la maquette, pièces du commerce achetées et ouvertes | E16, E19, E18 (arbitre sur maquette) |
| 17 au 30 novembre | quadrants reçus, assemblage 8 x 8, calibration complète, premier scan de 64 cases | E15, E17 |
| 1er au 13 décembre | portique sous le plateau, e2-e4, couloir, roque, Pi et moteur d'échecs | E20 à E24 |
| 14 au 21 décembre | batterie, caisse, surface finale, pièces définitives | E25, E26, E27 |
| 22 au 24 décembre | test final, emballage | E28 |
| 25 décembre | remise | E29 |
| 26 décembre au 25 janvier | publication, un épisode par jour, E30 en clôture | E30 (tourné entre Noël et le jour de l'an) |

Règle de montage pendant tout ce temps : un épisode monté au plus
tard une semaine après son tournage, par celui qui était en support.
Ce qui n'est pas monté sous une semaine est mis en attente et se
monte pendant l'attente des cartes (fin octobre), jamais en décembre.

## Ce que le dépôt fournit

Une bonne part des visuels existe déjà et se régénère
([runbook](../notes/08-regenerer.md)) :

- `docs/images/architecture.svg`, `stackup-blueprint.svg`,
  `frequency-plan.svg` : à recadrer en vertical pour les cartons.
- `docs/images/coil-board.png`, `analog-board.png`, `mockup-3d.png`,
  `piece-exploded.png`, `magnet-bracket.png` : rendus des cartes et
  de la mécanique, parfaits pour les match cuts avec le réel.
- `media/pitch/commun/` : la scène 3D des films (plateau, base chariot
  et horloge exportés de CadQuery, pièces Staunton dessinées sur les
  diamètres de base calculés), réutilisable pour tout plan d'objet.
- `python -m chessboard_calc report --pitch all` : les tables de
  fréquences et de diamètres pour « le chiffre ».
- Le routeur maison : enregistrer l'écran pendant une régénération
  donne un timelapse de routage (épisode E03).
- Le firmware : la sortie CSV en console et le dump `r` des 512
  échantillons donnent la courbe de ringdown à animer (E09).

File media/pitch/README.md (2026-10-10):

# Films de présentation

Les films qui présentent le projet (financement participatif, promo et
vlog Instagram et TikTok), faits avec [HyperFrames](https://github.com/heygen-com/hyperframes) :
chaque plan est une page HTML animée, rendue image par image en MP4.
Ils suivent la bible de la série ([docs/serie](../../docs/serie/README.md)) :
vertical 1080 x 1920, palette bois, encre, cuivre, ambre et cyan,
sous-titres dans la bande 1 300 à 1 550 px, signature sonore d'une note
par pièce, signature « Échec et Watt ».

## Versions

| Version | Dossier | État |
|---|---|---|
| « L'échiquier qui écoute ses pièces » : une pièce sans puce ni pile, reconnue à sa note, puis l'objet, puis la preuve | [ecoute/](ecoute/) | 9:16, 60 s, construite, plans d'objet en 3D |
| La même en 16:9 pour la page de financement | à créer (nouveau projet, même découpage) | à faire |
| « Une partie, du premier coup au mat » : le coup du berger joué sur le plateau, chaque coup révèle une fonction (détection, partie en ligne, arbitrage, horloge, prise) | [partie/](partie/) | 9:16, 53 s, construite, en 3D |
| « Le plateau se construit » : une seule caméra, le plateau démonté puis remonté couche par couche jusqu'aux pièces, puis posé sur la base chariot | [construction/](construction/) | 9:16, 54,5 s, construite, en 3D |

Le titre affiché suit la version. Voix off : plus tard, doublage ou
voix de synthèse (ElevenLabs), à décider ; les sous-titres de chaque
film (`compositions/captions.html`) sont écrits pour servir de script.

## La 3D

Les plans d'objet sont une scène Three.js unique, à la racine de chaque
film (`index.html`), calculée sur le temps global : une même image se
rend à l'identique à chaque recherche, ce que le rendu image par image
exige. Les compositions posent par-dessus les mots clés, les détails
mesurés et les sous-titres. Le code commun est dans
[`commun/scene3d.js`](commun/scene3d.js) :

- le plateau, la base chariot et l'horloge sont les solides CadQuery du
  dépôt, exportés en STL dans [`commun/meshes/`](commun/meshes/) par
  `mechanical/scenes.py --film-meshes` ;
- les pièces sont des Staunton tournées (le cavalier sculpté), posées
  sur les diamètres de base que calcule `chessboard_calc` ; leur
  hauteur suit `serie.piece_height_ratio` (valeurs de rendu, pas de
  conception) ;
- la pièce ouverte (feutre, bobine et condensateur, aimant, coque) est
  aux cotes de la classe ;
- les points lumineux sont aux positions `led_points` du plateau.

## Ce qui est commité, ce qui se régénère

Sont commités : les compositions (`index.html`, `compositions/`), le
dossier `commun/` (style, aides, police sous licence OFL, scène 3D et
maillages), `BRIEF.md` et `STORYBOARD.md`. Ne sont pas commités :
`assets/` (chiffres, sons, copie de `commun/`, régénérés), `renders/`
(les MP4), `snapshots/` (captures de relecture) et `node_modules/`.

Aucun nombre n'est écrit dans une composition : le texte porte
`data-fact="clé"` et la page le remplit depuis `assets/facts.js`, écrit
par `tools/serie` à partir de `config/board.yaml` ; la scène 3D lit ses
cotes dans `window.FACTS.scene`. `tests/test_serie.py` échoue si un
chiffre calculé apparaît tapé dans un film.

## Régénérer et rendre

Prérequis : Node 22 ou plus, FFmpeg, la CLI (`npm install -g hyperframes`)
et un Chrome sans interface (`hyperframes browser ensure`, ou dans un
environnement distant `PRODUCER_HEADLESS_SHELL_PATH` vers le Chromium
déjà installé). Pour un film donné (`ecoute`, `partie` ou `construction`) :

```bash
python mechanical/scenes.py --film-meshes media/pitch/commun/meshes  # si la géométrie a changé
python -m serie film media/pitch/partie   # chiffres, sons, commun/ dans assets/
cd media/pitch/partie
npm install                               # GSAP et three.js en local : le rendu ne touche pas le réseau
npx hyperframes check                     # lint, exécution, mise en page, contraste
npx hyperframes preview                   # Studio : relire et retoucher dans le navigateur
npx hyperframes render --fps 30 --quality delivery -o renders/partie-9x16.mp4
```

Le rendu 3D passe par le moteur logiciel du navigateur (SwiftShader)
quand il n'y a pas de GPU : compter une vingtaine de minutes par film à
30 i/s. Après une modification du yaml, relancer `python -m serie film` :
le film suit, sans retoucher les compositions.

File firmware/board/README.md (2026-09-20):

# Firmware du cerveau (STM32G474RE, quatre quadrants)

Dérivé du firmware de maquette (`firmware/mockup`), CMSIS nu sans HAL.
Il pilote le bus de commande commun aux quatre quadrants (adresses
A0..A2, enables des deux ADG1607, PULSE_EN, DAMP_EN_N), acquiert le
ringdown sur le convertisseur propre à chaque quadrant (ADC1 à ADC4,
un à la fois, 3,78 Méch/s, 512 points, FFT et interpolation), mesure
la voie B (comparateur plus capture de période) sur le quadrant 1, et
commande les 128 LED de camp en série.

## Construction

```bash
make            # build/board.bin (arm-none-eabi-gcc)
make NUCLEO=1   # build/nucleo/board-nucleo.bin, variante banc (section ci-dessous)
make NUCLEO=1 NUCLEO_FULL=1   # build/nucleo-full/board-nucleo-full.bin, un 4 x 4 sur le banc
make pins       # regénère src/board_pins.h depuis config/board.yaml
                # (PYTHONPATH=tools, la chaîne LED vient de quadgen.layout)
make flash      # rappel de la procédure ST-Link sur le connecteur SWD
```

`board_pins.h` est commité : refaire `make pins` après toute édition de
`plateau.brain.mcu_pins` ou de la géométrie des LED.

## Utilisation

Console sur USART1 (PA9/PA10), donc sur l'UART isolée : sur l'établi,
un adaptateur USB-UART sur l'embase Pi (J8) avec le cavalier JP1 côté
Pi ; plus tard, l'ESP32-S3 relaie le même flux en BLE et en WiFi.
115200 bauds, commande `h` pour l'aide. Sortie CSV :
`q,coil,sq,fa_hz,fb_hz,amp_mv,snr_db10` avec `sq = colonne + 8 x rangée`
(rangée 0 côté joueur, quadrants 1 et 3 à l'ouest, 2 et 4 à l'est
montés tournés).

- `s` : un scan des 64 cases ; `m` / `x` : scan répété marche/arrêt.
- `1`..`4` : scan d'un quadrant.
- `c` : calibration (16 mesures par case, moyennes en flash avec CRC).
- `i` : identification au plus proche voisin ; `l` : identification et
  allumage des LED (démo : classes paires au camp blanc, impaires au
  camp noir) ; `o` : extinction.
- `r` : dump brut des 512 échantillons du quadrant 1, bobine 1.
- `p` / `P` : durée d'impulsion d'excitation par pas de 100 ns.

## Séquence de mesure (par bobine)

1. Adresse sur le bus : mux, décodeur d'excitation et décodeur
   d'amortissement lisent le même index (A0..A2 plus MUX_EN_H comme
   quatrième bit) ; amortissement actif, ADC du quadrant sélectionné.
2. Relâchement de l'amortisseur ; PULSE_EN monte : le rail 12 V et la
   grille du FET de la bobine adressée s'activent ensemble (le 74HC4514
   est inhibé tant que PULSE_EN est bas).
3. Impulsion (1 µs par défaut), flyback dans le SS34FL.
4. Blanking 2 µs par amortissement actif, puis écoute.
5. Acquisition ADC (et captures comparateur sur le quadrant 1).
6. Ré-amortissement, libération des enables, FFT, ligne CSV.

## À vérifier au premier démarrage

- Codes COMP3 INMSEL (DAC3_CH1) et TIM2 TI4SEL (COMP3) dans `comp.c`,
  pris de mémoire du RM0440.
- Numéros de requête DMAMUX des ADC2 à ADC4 dans `adc.c` (36, 37, 38)
  et canaux d'entrée (ADC2_IN3 sur PA6, ADC3_IN12 sur PB0, ADC4_IN4 sur
  PB14), avec la fiche technique.
- Fonctions non couvertes par cette version : I2C vers la carte
  puissance, buzzer, LED d'état, bouton, chariot, et les messages de
  partie du protocole (`B`, `M`, `F`, `S`, [note 12](../../docs/notes/12-protocole.md)) :
  la console n'émet encore que les CSV de mesure, que le pont ESP32
  relaie tels quels.

## Variante banc : `make NUCLEO=1`

Le même firmware, compilé pour le banc de la
[note 19](../../docs/notes/19-cerveau-et-banc-nucleo.md) : une
Nucleo-G474RE (même MCU que le cerveau) reliée au quadrant réduit 2 x 2
par la carte de banc. Le bus, le cycle de mesure, la FFT, le
comparateur, la calibration et la CLI sont identiques ; ce qui change
vient de `board.h` et des constantes générées dans `board_pins.h` :

| | cerveau (`make`) | banc (`make NUCLEO=1`) |
|---|---|---|
| Quadrants | 4, de 16 bobines | 1, de 4 bobines (`plateau.quadrant.reduced`) |
| Console | USART1, PA9 et PA10, à travers l'ADuM1201 | USART2, PA2 et PA3, port série virtuel de la sonde ST-Link (`bench.console` du yaml) |
| Convertisseurs | ADC1 à ADC4 | ADC1 seul (PA0, comparateur COMP3 inchangé) |
| Chaîne LED | 128, quatre quadrants en série | 8, ordre du 2 x 2 (`NUCLEO_LED_CHAIN_SQ`) |
| Cases dans le CSV | a1 à h8 | a1, b1, a2, b2, soit 0, 1, 8, 9 |
| Commandes `2` à `4` | balayent un quadrant | refusées avec un commentaire |
| Sortie | `build/board.bin` | `build/nucleo/board-nucleo.bin` |

Un quadrant 4 x 4 complet se branche sur le même shield (même nappe,
même brochage, MUX_EN_H compris) : `make NUCLEO=1 NUCLEO_FULL=1` garde
tout ce qui précède et prend seize bobines par quadrant et la chaîne de
32 LED d'un quadrant posé à l'origine (`NUCLEO_FULL_LED_CHAIN_SQ`,
généré du même yaml), sortie `build/nucleo-full/board-nucleo-full.bin`.
Budget du banc et précaution sur les LED dans la
[note 19](../../docs/notes/19-cerveau-et-banc-nucleo.md), section 5.

Câblage du quadrant sur la Nucleo-64 : le bus du cerveau
(`plateau.brain.mcu_pins`) tombe sur l'embase Arduino, à une exception
près, DAMP_EN_N, dont le PC2 du cerveau n'atteint qu'un connecteur
Morpho : la variante le prend sur D6 (section `bench.signals` du yaml,
appliquée par `board.h`), ce qui permet une carte de banc sans
connecteur Morpho (`hardware/bench/`).

| Signal de la nappe | Broche | Sur la Nucleo |
|---|---|---|
| AMP_OUT | PA0 | A0 |
| PULSE_EN | PA4 | A2 |
| MUX_A0, MUX_A1, MUX_A2 | PB3, PB5, PB4 | D3, D4, D5 |
| MUX_EN_L | PC0 | A5 |
| MUX_EN_H | PC1 | A4 |
| DAMP_EN_N | PB10 (PC2 sur le cerveau) | D6 |
| LED_DIN | PA5 | D13 |
| 3V3, GND | | 3V3 et GND de la Nucleo |
| 5VA, 5V_LED, VIN | | la carte de banc (LDO 5 V, rail LED, jack 12 V) |

Flasher : copier `board-nucleo.bin` sur le lecteur NUCLEO, ou
`st-flash write build/nucleo/board-nucleo.bin 0x8000000`. Console : le
port série de la sonde, 115200 bauds, commande `h`. Deux broches ont
une seconde vie sur la Nucleo : PC13 (LED_STAT1 du cerveau) est le
bouton B1, PA5 (LED_DIN) la LED verte LD2 ; les LED d'état ne sont pas
pilotées par cette version et LD2 clignote au rythme des trames LED,
sans conséquence.

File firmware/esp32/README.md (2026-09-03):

# Firmware ESP32 : pont radio et horloge

Deux projets ESP-IDF (5.x) pour le module ESP32-S3-WROOM-1, plus un
composant commun.

| Dossier | Rôle |
|---|---|
| `common/` | analyseur de lignes du protocole (`proto.c`) et service Nordic UART sur NimBLE (`nus.c`), périphérique pour le pont, central pour l'horloge |
| `bridge/` | pont du cerveau : relais UART (STM32, 115200 bauds à travers l'ADuM1201) vers BLE, et retour ; WiFi et client Lichess plus tard |
| `clock/` | horloge à bascule : minuterie Fischer, Bronstein, simple ou libre, barre (deux microrupteurs), encodeur pour les presets, buzzer, écran ILI9341 2,4 pouces, liaison BLE au pont |

Le protocole est décrit dans `docs/notes/12-protocole.md`.

## État

- La logique de l'horloge (`clock/main/chessclock.c`) est testée sur
  PC : `cc -Iclock/main clock/test/test_chessclock.c clock/main/chessclock.c && ./a.out`.
  L'analyseur de lignes compile en C standard.
- Les parties ESP-IDF (NimBLE, UART, LEDC, esp_lcd) sont écrites contre
  l'API d'ESP-IDF 5.2 mais **ne sont pas compilées par la CI** du dépôt
  (pas de chaîne ESP-IDF). Première compilation à faire sur poste :

```bash
. ~/esp/esp-idf/export.sh
cd firmware/esp32/bridge && idf.py set-target esp32s3 && idf.py build flash monitor
cd firmware/esp32/clock  && idf.py set-target esp32s3 && idf.py build flash monitor
```

## Broches

Pont (module du cerveau) : UART1 sur IO17 (TX) et IO18 (RX) vers
l'ADuM1201, la console USB du module reste libre pour le débogage.

Horloge : voir `ESP_PINS` dans `tools/boardgen/clock.py` (écran SPI2
sur IO15/16/17 avec CS IO4, DC IO5, RST IO6, rétroéclairage IO7 ;
barre IO12 blancs et IO13 noirs ; encodeur IO9/IO10, poussoir IO11 ;
buzzer IO14).

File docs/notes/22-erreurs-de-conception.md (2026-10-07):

# 22. Erreurs de conception des cartes, et ce qui empêche de les refaire

Cette note liste les erreurs réellement commises sur les cartes de ce
projet, pas les erreurs possibles en général. Chacune est écrite de la
même façon : le fait, ce qui l'a révélée, la cause, puis la correction
et le garde-fou. Le garde-fou est la partie qui compte : une erreur
comprise mais laissée sans contrôle automatique revient au build
suivant, et celles qui suivent sont revenues plusieurs fois avant
d'être verrouillées.

Règle du projet, tirée de cette liste : **une erreur trouvée devient
un contrôle qui tourne**, dans le build ou dans les tests. Les
commandes qui font tourner ces contrôles sont rassemblées à la fin.

## 1. Le compte des liaisons manquantes était faux

**Le fait.** Le build annonçait sept liaisons ouvertes sur la carte
analogique, KiCad en comptait vingt-huit. Pendant des jours, les sept
ont servi de repère : on décidait quoi faire, quoi lâcher et quand
s'arrêter sur un chiffre faux.

**Ce qui l'a révélée.** L'ouverture de la carte dans KiCad, avec le
chevelu affiché, après remplissage des zones (touche B).

**La cause.** Trois écarts dans le modèle du générateur, chacun
optimiste : la masse n'était pas vérifiée du tout, deux morceaux de
cuivre sur des couches différentes étaient comptés reliés sans exiger
de via, et une pastille valait la boîte rectangulaire autour d'elle et
non son cuivre réel.

**La correction et le garde-fou.** Le modèle exact du quadrant
(`tools/quadgen/connect.py`) est devenu la comptabilité unique,
importée par les trois générateurs
([note 04](04-routeur-et-garanties.md)) : forme vraie des pastilles,
union par couche, via obligatoire pour changer de couche, plan de masse
calculé îlot par îlot. Le test
`test_the_exact_check_counts_the_pieces_kicad_would` épingle les cas
qui avaient menti (piste qui s'arrête court, changement de couche sans
via, plan coupé en deux). Depuis, le compte du build est celui que
KiCad affiche, et c'est ce qui a permis de passer de 28 à 0.

**La leçon.** Un mauvais arbitre fait prendre les mauvaises décisions
pendant longtemps. La « saturation » qui justifiait de s'arrêter à sept
liaisons n'existait pas : elle était un artefact du compte.

## 2. Le plan de masse pris pour une bande idéale

**Le fait.** Dix-neuf des vingt-huit liaisons manquantes étaient des
masses. Le générateur posait un plan sur une couche et considérait
toute pastille de masse comme reliée à lui.

**Ce qui l'a révélée.** Le compte exact du point 1, une fois le plan
calculé comme le calcule le remplisseur de KiCad.

**La cause.** Un plan traversé par des pistes de la face arrière n'est
plus une bande : c'est une collection d'îlots, et deux pastilles posées
sur deux îlots ne sont pas reliées. Sur les cellules de bobine, quatre
lignes traversent la cellule par la face arrière et découpent son plan
en confettis.

**La correction et le garde-fou.** Le plan est calculé en géométrie
exacte, îlot par îlot, garde 0,3 mm et largeur minimale 0,2 mm, puis
une passe de finition de la masse descend chaque groupe de pastilles
orphelin vers l'îlot qui porte le reste. Là où le découpage est
structurel, une **épine de masse** est tracée avant le routage (une par
cellule, dans le canal de 1,1 mm entre l'écrêteur et la résistance de
grille). Le compte du point 1 vérifie le résultat.

## 3. Une pastille à 1 mm hors du contour, depuis l'origine

**Le fait.** La broche 2 du jack d'alimentation de la carte analogique
était à 1 mm en dehors du contour de carte. Le fabricant aurait fraisé
la carte au milieu de la pastille.

**Ce qui l'a révélée.** `tools/drc.py`, c'est à dire le DRC de KiCad en
ligne de commande, une fois le routage fermé et le contrôle lancé sur
toutes les familles de règles et non sur la seule connexité.

**La cause.** Le générateur vérifiait ce qu'il traçait (gardes entre
cuivres) mais pas ce qu'il plaçait par rapport au bord. Un jack de
panneau dépasse légitimement du contour par son corps, ce qui rendait
le défaut invisible sur le rendu.

**La correction et le garde-fou.** Le jack est reculé à x = 8 mm, ses
pastilles à 0,5 mm du bord, le corps dépassant à l'ouest comme le veut
sa fonction. Le garde-fou est le DRC de KiCad lui même, inscrit dans le
runbook ([note 08](08-regenerer.md)) et lancé sur chaque carte avant
tout export, avec la garde au bord réglée à la valeur de fabrication.

## 4. Quatre couches déclarées pour une carte à deux couches

**Le fait.** Le fichier de la carte analogique déclarait quatre couches
cuivre. L'archive de fabrication portait donc deux couches internes
vides. Un fabricant aurait facturé et gravé une carte quatre couches.

**Ce qui l'a révélée.** La relecture de l'archive produite, fichier par
fichier, au moment de la première commande.

**La cause.** `coilgen.kicad.Board` a quatre couches par défaut, pour
la carte bobines ; le générateur analogique ne redéfinissait pas ce
paramètre.

**La correction et le garde-fou.** `copper_layers=2` dans le
générateur, et surtout `tools/gerbers.py` qui lit la pile de couches
**sur la carte** au lieu de porter une liste par projet, plus le test
`test_the_generated_archives_carry_the_stack_the_board_declares` qui
compare les fichiers de l'archive à la pile que le `.kicad_pcb`
déclare. Une couche oubliée ou une couche en trop est désormais un
test rouge.

## 5. Quarante-neuf chevauchements de courtyard

**Le fait.** Quarante-neuf paires de composants se disputaient la même
place sur la carte analogique, dont quarante-quatre dans le motif de
cellule répété quatre fois. Ce n'est pas un court-circuit et aucune
règle de cuivre n'en parle : c'est une reprise à l'assemblage, des
pièces qui ne tiennent pas côte à côte et des condensateurs que la buse
de refusion pousse hors de leurs pastilles.

**Ce qui l'a révélée.** Le DRC de KiCad, famille `courtyards_overlap`,
que le générateur ne regardait pas.

**La cause.** Le motif de cellule espaçait ses rangées sur la taille
des pastilles (3 mm) alors que les courtyards des boîtiers en demandent
3,3 à 4,2 selon le boîtier.

**La correction et le garde-fou.** Les rangées sont réespacées (la
cellule est 1,7 mm plus haute et tient toujours entre le rail VREF et
le connecteur de bobines), et cinq voisinages serrés sont corrigés un
par un. Le build lit maintenant les courtyards des empreintes, les
pose, et compte les paires qui se recouvrent
(`tools/analoggen/yards.py`) : le nombre sort sur la ligne d'état à
côté des liaisons ouvertes, et le test
`test_no_two_courtyards_of_the_analog_board_overlap` exige zéro.

**La leçon.** Le placement se vérifie comme le routage. Le prix de
cette correction a été de rejouer tout le routage de la carte, donc de
rouvrir des liaisons ailleurs : un défaut de placement se paie en
routage.

## 6. Des liaisons structurelles dessinées à l'oeil

**Le fait.** Les liaisons que le routeur ne trouve pas sont tracées à
la main dans le générateur, avant le routage. Chaque fois qu'une de ces
routes a été posée d'après un rendu au lieu d'une mesure, elle a cassé
quelque chose : une amorce qui croise une autre sur la même couche, un
via qui touche une pastille voisine, une voie qui passe à 0,05 mm d'un
bord de pastille.

**Ce qui l'a révélée.** Au début le DRC, après chaque build de trente
minutes. Beaucoup trop tard.

**La cause.** Une route à la main est une hypothèse sur la géométrie.
Sans contrôle, l'hypothèse est vérifiée trente minutes plus tard, ou
jamais.

**La correction et le garde-fou.** Les fonctions qui posent une amorce
(`T` et `V` dans `_hand_seeds`) revérifient chaque segment et chaque
via, au build, contre la géométrie réelle de toutes les pastilles et
contre les autres amorces, et lèvent une erreur nommée
(`seed C4_B crosses seed C4_A on B.Cu`) avant que le routage ne
commence. Le test
`test_the_hand_seeds_of_the_analog_board_stay_legal` rejoue ce contrôle
en deux secondes. Toutes les coordonnées des amorces sont dérivées des
bords de pastilles mesurés (`edge`, `channel_x`, `P`), jamais écrites
en dur.

## 7. L'ordre de routage : la liaison la plus longue passe en dernier

**Le fait.** Les liaisons qui restaient ouvertes build après build
étaient toujours les mêmes familles : la ligne A de la cellule 4, la
ligne B de la cellule 4, la grille d'amortissement de la cellule 2,
c'est à dire les parcours les plus longs de la carte.

**Ce qui l'a révélée.** La liste des liaisons ouvertes, en la lisant
comme une donnée plutôt que comme une fatalité : ces nets traversent la
carte, et la bande qu'ils doivent traverser est pleine quand leur tour
vient.

**La cause.** Le routeur trie les nets par portée croissante : les
courts d'abord, les longs ensuite, dans une bande déjà saturée. La
congestion dépend de l'ordre, et rien ne rattrapait un net arrivé trop
tard.

**La correction et le garde-fou.** Trois mesures cumulées : le routeur
joue trois tours et chaque tour promeut en tête ce que le précédent a
manqué (le meilleur tour est gardé) ; les parcours structurellement
impossibles reçoivent leur voie avant le routage (point 6) ; et ce qui
reste passe par la passe de finition puis par le labyrinthe. Le bilan
final est imprimé par le build, liaison par liaison, avec les
pastilles de chaque morceau.

**La leçon.** Une liaison qui échoue n'est presque jamais un hasard à
relancer. C'est un ordre, un mur, ou un couloir trop étroit, et les
trois se mesurent.

## 8. Le labyrinthe qui renonçait sur les longues traversées

**Le fait.** Le labyrinthe (recherche A* en géométrie exacte, dernier
recours quand aucun raccord simple ne passe) rendait « pas de chemin »
sur les liaisons qui traversent la carte, alors qu'un chemin existait.

**Ce qui l'a révélée.** Un appel direct du labyrinthe sur la liaison
restante, hors du build, qui répondait en 0,2 s : trop vite pour une
recherche, donc un abandon et non un échec.

**La cause.** Une trame de 0,05 mm sur une fenêtre de 57 par 61 mm fait
1,4 million de cellules, au delà du plafond d'exploration.

**La correction et le garde-fou.** La fenêtre est dégrossie (0,1 puis
0,2 mm) jusqu'à tenir sous le plafond. Le chemin trouvé est de toute
façon revérifié en géométrie exacte avant d'être posé, donc une trame
grossière coûte du détail et jamais de la légalité. Test :
`test_the_maze_coarsens_its_raster_for_a_haul_across_the_board`.

## 9. Un via ne rentre pas dans 0,85 mm

**Le fait.** La rangée B de la cellule 4 restait isolée. Le labyrinthe
confirmait qu'aucun chemin n'existait, sur les deux couches.

**Ce qui l'a révélée.** La mesure de ce qui l'enfermait, cuivre par
cuivre : la ligne de grille du mux en face avant à x = 76,75, la ligne
d'excitation de la cellule 1 qui traverse toute la carte en face
arrière à x = 75,50, la masse à x = 77,72. Reste 0,85 mm entre deux
murs, et un via de 0,6 mm avec sa garde de 0,15 mm en demande 0,9.

**La cause.** Deux causes en une : la descente n'était pas réclamée
avant le routage, et le raisonnement cherchait un passage en face avant
là où la face avant était pleine.

**La correction et le garde-fou.** La descente est tracée avant le
routage, par la face arrière de la bande : l'écrêteur du rail 5VA et le
FET d'excitation sont tous les deux en CMS, donc **ils ne bloquent que
la face avant**, et la face arrière de cette bande est vide d'une
rangée à l'autre. Deux vias, une descente droite, coordonnées dérivées
des bords de pastilles.

**La leçon, deux fois utile.** Une pastille CMS ne bloque qu'une
couche ; un passage introuvable en face avant est souvent libre en face
arrière. Et avant de dessiner, mesurer les murs : la largeur du couloir
se calcule, elle ne s'estime pas.

## 10. Une archive de fabrication qui ne correspondait plus à sa carte

**Le fait.** `hardware/mockup-2x2/coil-board/coil-board-gerbers.zip`
était commité, plus ancien que le `.kicad_pcb` à côté de lui, et tracé
depuis un état de la carte qui n'existe plus. La carte, dans son état
commité, porte 251 violations bloquantes au DRC (96 gardes, 82 gardes
de perçage, 63 ponts de masque, 8 perçages trop proches) et deux
éléments non connectés. Rien dans un zip ne dit de quelle carte il
vient : cette archive était prête à être commandée.

**Ce qui l'a révélée.** L'audit avant commande : comparer la date de
chaque archive à celle de sa carte, puis passer le DRC sur les cartes
dont une archive est commitée.

**La cause.** Le script d'export de cette carte appelait `kicad-cli`
directement, avec une liste de couches écrite à la main, sans remplir
les zones et **sans le garde de connexité** que
`tools/gerbers.py` applique aux autres cartes. Un chemin parallèle
échappe aux contrôles du chemin principal.

**La correction et le garde-fou.** Le script d'export de la carte
bobines appelle maintenant `tools/gerbers.py` comme les autres, donc le
garde refuse d'exporter tant que le routage n'est pas fermé, et
l'archive obsolète est retirée du dépôt (elle sera regénérée quand la
carte passera le DRC). En plus, `tools/gerbers.py` écrit à côté de
chaque archive un fichier au format `sha256sum` qui porte l'empreinte
de la carte tracée et celle de l'archive :

```bash
cd hardware/bench && sha256sum -c bench-gerbers.sha256
```

Le test `test_every_archive_records_the_board_it_was_plotted_from`
compare ces empreintes à ce qui est commité : une archive qui cesse de
correspondre à sa source est un test rouge, et non un fichier que
personne ne regarde deux fois.

## 11. Un BOM d'assemblage silencieusement partiel

**Le fait.** Les fichiers `jlc-bom.csv` ne portent que les lignes qui
ont un code LCSC. Sur le quadrant 2 x 2, cela fait 38 composants sur
126 : les résistances et condensateurs génériques, les BAV99W, et
surtout le multiplexeur ADG1607 n'y sont pas. Téléversé tel quel, un
ordre d'assemblage aurait posé 38 composants et laissé les 88 autres à
souder à la main, dont des 0603.

**Ce qui l'a révélée.** La comparaison du BOM complet (`bom.csv`) avec
le BOM d'assemblage (`jlc-bom.csv`), référence par référence. La parité
entre BOM et CPL, elle, était parfaite sur toutes les cartes, et c'est
justement ce qui cachait le trou : les deux fichiers viennent de la
même source, donc ils sont d'accord sur un sous ensemble incomplet.

**La cause.** Le code LCSC est facultatif dans la description de
circuit, et les lignes sans code sont filtrées à l'export sans être
signalées.

**La correction et le garde-fou.** Tant que les codes ne sont pas
complétés, la commande se fait en **cartes nues**, ce qui est le
chemin normal en prototypage ; le détail par carte et la liste exacte
des lignes à compléter sont dans la
[note 23](23-commande-jlcpcb.md). La règle : ne jamais lire la parité
BOM contre CPL comme une preuve de complétude, et compter les
composants du BOM d'assemblage contre ceux de la carte.
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

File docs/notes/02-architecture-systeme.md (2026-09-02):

# 02. Architecture système et budget de bruit

## Vue d'ensemble

Le système final : un plateau qui identifie les pièces (LC passifs,
[note 01](01-principe-de-mesure.md)), les déplace par un aimant N42
sur un portique CoreXY sous le plateau, et affiche le camp occupant
chaque case par deux points lumineux (ADR 0009). Cerveau temps réel :
STM32G474 ; un Raspberry Pi Zero 2 W optionnel (moteur d'échecs,
réseau) parle au MCU par UART isolée. La maquette 2 x 2 de phase 1
matérialise la chaîne de mesure complète et les LED, sans portique.

## Le plateau 8 x 8 (ADR 0010)

Un module plateau invariant (contreplaqué plus quatre quadrants 4 x 4
identiques, chacun avec ses 16 spirales, 32 LED et son frontal
analogique en bande de bord) posé dans une base fine (21 mm) ou une
base chariot (54 mm, CoreXY et ailes de capture). Au fond de la base :
cerveau (STM32G474 soudé, quatre nappes de quadrant, LED, alimentation
bas niveau, emplacement ESP32-S3 et Pi), carte puissance (BMS 3S,
USB-C PD) et trois cellules plates. Une horloge à bascule séparée,
en BLE, choisit les modes et affiche les temps. Détail et raisons dans
la [note 10](10-plateau-8x8-et-horloge.md).
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

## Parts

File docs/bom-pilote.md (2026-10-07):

# Fiche du pilote simple : une carte bobines 100 x 100 et un shield à la main

Établie le 07/10/2026. Elle répond à une commande précise : **un pilote
avec le minimum de composants, qui tienne dans le palier 100 x 100 mm
avec une seule carte à concevoir, le traitement sur un shield posé à
côté de la Nucleo et soudé à la main.** Les quantités sortent des
nomenclatures générées, les prix des relevés du 20/09/2026
(`docs/prix-plateau.csv`, [fiche de la maquette](bom-maquette.md)),
conversion 1 USD = 0,92 EUR, TVA 20 % ajoutée. Aucune commande n'a été
passée.

## 1. Ce qu'est le pilote

| Élément | Choix | Pourquoi |
|---|---|---|
| Carte à concevoir | une seule : la [carte bobines](../hardware/mockup-2x2/coil-board/README.md), 100 x 100 mm, 4 couches, passive (quatre spirales, un connecteur 1 x 12, huit trous) | à p = 50 mm, quatre cases font exactement 100 x 100 : il n'y a de place ni pour un frontal ni pour une LED de plus sans sortir du palier ([note 16](notes/16-cout-des-cartes.md), section 3) |
| Pas | p = 50 mm, celui du plateau (ADR 0010) | un pilote à p = 40 ne validerait pas le plateau |
| LED de camp | aucune (`mockup.coil_board.leds.fitted: false`) | seize composants et toute la chaîne de données en moins ; c'est aussi ce qui a fermé le DRC de la carte |
| Frontal | sur un shield soudé à la main, trois options au paragraphe 3 | le signal brut de spirale traverse 10 à 15 cm de nappe, acceptable sur un pilote de paillasse, refusé sur le plateau (ADR 0004) |
| Contrôleur | NUCLEO-G474RE, le MCU du cerveau, firmware `make NUCLEO=1` | rien à souder de fin, sonde et port série compris |
| Pions | quatre pucks de test (pion, cavalier, fou, tour noirs) | le bas de la bande, les notes les plus serrées ([note 20](notes/20-tuto-banc.md)) |

Ce pilote est la maquette de l'ADR 0008 allégée : même carte bobines,
sans LED, et son frontal au choix. Il mesure le couplage spirale-pièce
à travers 7,1 mm d'entrefer, le facteur Q des pucks et la séparation
des notes, avec le firmware du cerveau ; il ne mesure ni les LED, ni la
nappe FPC, ni le frontal embarqué du quadrant.

## 2. La carte, ce qu'elle coûte

| Poste | EUR TTC | Détail |
|---|---|---|
| 5 cartes bobines nues, 4 couches, 100 x 100 | 8 à 15 | 1,6 mm, 1 oz externe, HASL sans plomb |
| Option cuivre interne 1 oz | 10 à 25 | la spirale du modèle ; en 0,5 oz standard l'ESR monte de 50 % et le Q perd un tiers ([note 23](notes/23-commande-jlcpcb.md), 3.1) : payer, ou corriger le yaml avant de mesurer |
| Barrette 1 x 12 au pas 2,54 | 0,1 | la seule pièce de la carte, soudée à la main |

Les gerbers et leur empreinte sont commités
(`coil-board-gerbers.zip`, `coil-board-gerbers.sha256`), DRC KiCad à
zéro erreur et zéro élément non connecté.

## 3. Le shield : trois options

Le shield fait trois choses : frapper chaque bobine (rail 12 V commuté,
un FET par bobine), écouter la sonnerie (mux différentiel, gain,
filtrage) et donner à la Nucleo ses signaux (A0 pour l'ADC, D3 à D15
pour les commandes). Les trois options partagent le même circuit, celui
de l'ADR 0008 ; elles diffèrent par le support.

### Option A, conseillée : la carte analogique existante, soudée à la main

La [carte analogique de la maquette](../hardware/mockup-2x2/analog-board/README.md)
est ce shield, déjà conçu, routé et au DRC zéro, 100 x 62 mm en deux
couches (palier 100 x 100), avec ses gerbers commités. Rien à
concevoir : c'est une seconde carte à commander, pas un second design.
Tout se soude au fer sauf le buck TPS62150 (QFN), que le pilote ne
monte pas.

| Bloc | Monter | Laisser vide |
|---|---|---|
| Entrée 12 V | jack J1, SS34 D1, TVS D2, réservoir C1 et C2 | |
| Rail 5VA | LDO U2 LP2985 et ses C9, C10, C11, C12 ; cavalier JP1 en position LDO | buck U1, L1, JP3, R1 à R4, C4 à C8, C27, perle FB1 |
| Cellules bobine (x 4) | 10 k x 2, 330 R x 2, BAV99 x 2, B5819W, AO3400A, SS34, AO3401A, 680 R, 100 k x 2 | |
| Commutateur de rail | Q1 AO3401A, Q2 AO3400A, R7, R8, R10, R9 10 R en 2512 | |
| Mux et chaîne | U3 74HCT4052, U4 AD8421 (R14 fixe le gain 20), U5 et U6 OPA2810, leurs résistances et condensateurs, R5, R6, C13 du VREF | |
| UART Pi isolée | | U7 ADuM1201, C26, J5 ; R66 et R67 restent non montées |
| LED | | U8 74AHCT1G125, R68 |

| Poste | EUR TTC | Détail |
|---|---|---|
| 5 cartes analogiques nues, 2 couches, 100 x 62 | 2 à 5 | HASL sans plomb suffit |
| Composants montés, compte exact | 18 | 16,3 USD : OPA2810 x 2 à 5,48 (Mouser), AD8421 3,69, 74HCT4052 0,15, LP2985 0,17, FET et diodes 1,2, passifs 0,6, jack et barrettes 0,4 |
| Les mêmes avec la rechange de 10 % par ligne | 30 | la rechange double les circuits à l'unité |
| Port des composants | 15 à 25 | LCSC, plus Mouser ou DigiKey pour l'OPA2810 |

### Option B : perfboard ou shield de prototypage Nucleo, câblé à la main

Les mêmes composants que l'option A, sans la carte : les boîtiers CMS
passent sur des adaptateurs (SOIC-8 vers DIP x 3, TSSOP-16 x 1 ou un
74HCT4052N en DIP-16, SOT-23 x 10 ou des FET TO-92 : BS170 pour
l'AO3400A, BS250 pour l'AO3401A) sur une plaque de prototypage
Nucleo-64 ou une perfboard, 8 à 12 EUR d'adaptateurs et de plaque.

C'est l'option qui respecte à la lettre « un seul design de PCB », et
c'est celle que cette fiche déconseille : deux OPA2810 à 105 MHz en
Sallen-Key et un AD8421 à gain 20 sur une plaque à trous, c'est une
journée de câblage et un risque sérieux d'oscillation et de bruit, sur
la mesure même que le pilote doit établir. Elle reste valable pour un
premier essai sans chaîne de gain (paragraphe 6).

### Option C : un shield minimal à concevoir

Une chaîne single-ended sur l'amplificateur interne du STM32G474 (PGA
jusqu'à x 64, 13 MHz de produit gain-bande) et son comparateur
(ADR 0007), un seul 74HC4051, les quatre FET d'excitation, sans
AD8421, sans OPA2810, sans amortisseurs : une trentaine de composants.
Elle n'existe pas : c'est une conception (deux à trois jours, une ADR,
le firmware de la voie comparateur) qui change l'architecture de
mesure que les quadrants reprennent. À ouvrir seulement si la première
mesure du paragraphe 6 montre que la chaîne de l'ADR 0008 est
surdimensionnée.

## 4. Le reste

| Poste | EUR TTC | Détail |
|---|---|---|
| NUCLEO-G474RE | 21 | eStore ST ou RS, 17,50 EUR HT |
| Nappes Dupont femelle-femelle x 20 | 3 | J4 du shield vers les embases Arduino de la Nucleo ([README de la maquette](../hardware/mockup-2x2/README.md), paragraphe 3) |
| Alimentation 12 V | 0 ou 10 | de laboratoire limitée en courant, sinon un bloc 12 V 2 A à jack 5,5 x 2,1 ; jamais un chargeur à découpage près des bobines |
| Quatre pucks | 24 à 30 | aimants ferrite Y30, fil émaillé 0,25 et 0,315 mm, C0G 1 % 0805, impression PETG, vis M3 x 30 ([note 20](notes/20-tuto-banc.md), 3.5) |
| Surface de jeu | 13 | contreplaqué sec 3 mm, feutre 0,5 mm, entretoises et visserie M3 nylon |
| Outillage | 0, ou 200 à 400 | fer fin, multimètre, alimentation, oscilloscope de poche 10 MHz, LCR-mètre, perceuse pour bobiner ; l'air chaud n'est plus nécessaire, le QFN n'est pas monté |

## 5. Totaux

| Scénario | EUR TTC |
|---|---|
| Carte bobines seule, 5 pièces, port compris | 26 à 43, plus 10 à 25 pour le cuivre interne |
| Pilote complet, option A, rechange comprise, outillage déjà là | **130 à 195** |
| Pilote complet, option B | 140 à 205 |
| Le même pilote sur le quadrant 2 x 2 avec son frontal embarqué (fiche du 07/10) | 220 à 283 |

Détail du scénario A : cartes 10 à 20, cuivre interne 10 à 25, port et
TVA des cartes 18 à 28, composants 30, port des composants 15 à 25,
Nucleo et nappes 24, pucks 24 à 30, surface 13. Ce qui pèse : les deux
OPA2810 et l'AD8421 (14,65 USD sur 16,3), le port, et l'option cuivre
interne, qui coûte plus que la carte qu'elle améliore.

## 6. Ce que le modèle dit du signal, et la première mesure

`chessboard_calc.coupling.ringdown_signal` donne, pour une pièce sur sa
case à travers 7,1 mm d'entrefer, la force électromotrice attendue sur
la spirale après les 2 µs de silence :

| Pièce | Note | EMF sur la spirale |
|---|---|---|
| pion noir | 217 kHz | 0,12 V crête |
| cavalier noir | 237 kHz | 0,21 V |
| fou noir | 262 kHz | 0,23 V |
| tour noire | 288 kHz | 0,37 V |
| roi blanc | 613 kHz | 0,74 V |

Avec le gain de 200 à 400 de la chaîne de l'ADR 0008, ces amplitudes
donnent 24 à 150 V en sortie : la chaîne sature à 3,3 V dès le premier
pion. Soit le modèle surestime d'un facteur dix à cinquante, soit le
gain est trop fort d'autant. C'est la première chose que le pilote
mesure, et elle ne demande aucun shield : un FET d'excitation sur une
plaque d'essai, la Nucleo qui le commande, et l'oscilloscope directement
sur une borne de spirale, un puck posé sur la case. L'amplitude lue
décide entre l'option A telle quelle, l'option A avec le gain de
l'AD8421 ramené à 1 (R14 retirée), et l'option C.

## 7. Dans l'ordre

1. Commander les cartes bobines (paragraphe 2), et la carte analogique
   avec elles si l'option A est retenue : même panier, même port.
2. Pendant la fabrication : bobiner les quatre pucks, imprimer les
   gabarits, percer le contreplaqué au gabarit `surface-template`.
3. À réception : la mesure du paragraphe 6, à l'oscilloscope, sans
   shield.
4. Souder le shield de l'option retenue, brancher la Nucleo, dérouler
   les échelons de la [note 20](notes/20-tuto-banc.md) avec le firmware
   en `make NUCLEO=1`.
5. Noter dans le [journal](notes/09-journal.md) les prix obtenus et
   l'amplitude mesurée : c'est elle qui décide de la suite, quadrant
   avec frontal embarqué ou tuile 100 x 100 avec frontal centralisé.

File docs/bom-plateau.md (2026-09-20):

# Fiche d'approvisionnement du plateau : quatre quadrants et le cerveau

Établie le 20/09/2026. Elle répond à une question précise : que faut il
acheter, et où, pour monter le plateau 8 x 8 de l'ADR 0010, c'est à dire
**quatre quadrants 4 x 4 identiques et un cerveau**. La maquette 2 x 2 a
la sienne ([fiche de la maquette](bom-maquette.md)), même méthode, mêmes
conventions de prix.

Les quantités ne sont pas recopiées : elles sortent des `bom.csv`
générés par `quadgen` et `boardgen`, agrégés par `tools/bomagg.py`. Les
prix, eux, sont des données de marché, ils vieillissent, et chaque ligne
porte son statut (`verified` ou `estimated`) et sa source dans
`docs/prix-plateau.csv`. Conversion retenue, celle de la fiche de la
maquette : 1 USD = 0,92 EUR. Les prix asiatiques sont hors taxe, la TVA
de 20 % est collectée à la commande (IOSS) ou à l'import ; elle est
ajoutée dans les totaux en EUR TTC.

**Ce que cette fiche n'est pas.** Aucune commande n'a été passée. Le
réseau de cet environnement bloque les sites distributeurs et leurs API
(le point était déjà noté sur la maquette) : les relevés viennent de
recherches web du 20/09/2026, les paniers sont préparés au format
d'import de chaque site, et les prix se revalident au panier avant de
payer.

## 1. La liste, en une commande

```bash
python3 tools/bomagg.py --prices docs/prix-plateau.csv \
    --csv docs/bom-plateau.csv --carts docs/
```

```
quadrant       x4   1296 components   80 pads (test points, ties, holes)
brain          x1    103 components   10 pads (test points, ties, holes)
total               1399 components in  71 purchase lines, 1584 units to buy with spares
basket lcsc          138.09 USD over  70 of 71 lines
basket mouser        378.80 USD over  70 of 71 lines
basket mixed         180.05 USD over  71 of 71 lines
one quadrant          32.44 USD of parts,  35 lines, exact count without spares
one brain             18.63 USD of parts,  50 lines, exact count without spares
```

Trois fichiers sortent de là, tous commités :

| Fichier | Contenu |
|---|---|
| [`bom-plateau.csv`](bom-plateau.csv) | les 71 lignes d'achat, quantité par carte, total, quantité à acheter, prix des deux canaux |
| [`panier-lcsc.csv`](panier-lcsc.csv) | 68 lignes au format d'import BOM de LCSC |
| [`panier-mouser.csv`](panier-mouser.csv) | 3 lignes au format d'import BOM de Mouser |

Les 1 399 composants se comptent comme la [note 23](notes/23-commande-jlcpcb.md) :
les points de test, les amarres de spirale et les trous de fixation sont
des pastilles, pas des composants, et ne sont pas dans la liste (90 sur
le plateau). Les 1 584 unités à acheter ajoutent la règle de rechange :
10 % par ligne, jamais moins de un, jamais moins de deux dès dix pièces.
Elle coûte 31,66 USD sur ce panier, soit 21 % : c'est le prix de ne pas
attendre trois semaines pour un AO3400A perdu sous l'établi.

## 2. Ce que la liste coûte

| Panier | USD | EUR HT | EUR TTC | Couverture |
|---|---|---|---|---|
| Tout LCSC | 138,09 | 127,04 | 152,45 | 70 lignes sur 71, l'OPA2810 n'y est pas |
| Tout Mouser | 378,80 | 348,50 | 418,20 | 70 lignes sur 71, la WS2812B n'y est pas |
| **Panaché, le moins cher ligne à ligne** | **180,05** | **165,64** | **198,77** | **71 sur 71** |

Le panier LCSC est le moins cher **et** incomplet : il ne totalise pas
l'OPA2810, que LCSC ne catalogue pas, et l'OPA2810 pèse 49 USD. Un total
partiel qui se lit comme un total complet est exactement l'erreur 11 de
la [note 22](notes/22-erreurs-de-conception.md) ; c'est pourquoi l'outil
affiche la couverture à côté de chaque total, et pourquoi un test exige
qu'aucune ligne ne soit sans prix.

Par carte, composants seuls, au compte exact et sans rechange :

| Carte | Composants | Lignes | Prix des composants | Ce que la note 23 estimait |
|---|---|---|---|---|
| Un quadrant 4 x 4 | 324 | 35 | 32,44 USD, soit 29,84 EUR HT | 41 à 46 EUR |
| Le cerveau | 103 | 50 | 18,63 USD, soit 17,14 EUR HT | 26 EUR |

La [note 23](notes/23-commande-jlcpcb.md), paragraphe 8.2, surestimait
donc d'un tiers, pour une raison simple : elle comptait l'ADG1607 à
8,5 EUR et l'AD8421 jusqu'à 8,2 EUR, prix catalogue occidentaux, alors
que le premier se trouve à 5,12 USD et le second à 3,69 USD chez LCSC.
Le silicium analogique des quatre quadrants fait 99,56 USD au compte
exact et 113,85 USD rechange comprise (105 EUR HT), et non 120 à
140 EUR.

## 3. Les six lignes qui font la facture

| Ligne | Quantité achetée | Coût | Part du panier |
|---|---|---|---|
| OPA2810IDR | 9 | 49,32 USD | 27,4 % |
| ADG1607BCPZ | 9 | 46,08 USD | 25,6 % |
| AD8421ARZ | 5 | 18,45 USD | 10,2 % |
| STM32G474RET6 | 2 | 11,00 USD | 6,1 % |
| FH12-16S-0.5SH(55) | 9 | 10,80 USD | 6,0 % |
| WS2812B | 141 | 8,69 USD | 4,8 % |

**Trois références du frontal analogique font 63,2 % du panier.** C'est
la mesure que la [note 16](notes/16-cout-des-cartes.md), section 2,
attendait pour rouvrir la question du différentiel vrai contre le
single-ended : le poste à discuter n'est ni les 1 399 composants, ni les
128 LED, c'est le mux, l'ampli d'instrumentation et les deux AOP, deux
fois par quadrant pour les deux derniers.

À l'autre bout, les 735 passifs génériques (condensateurs et résistances
0402 à 2010, sans référence fabricant) coûtent 2,85 USD chez LCSC,
rechange comprise, contre 20,42 USD chez Mouser. Sept fois plus cher,
pour 1,6 % du panier : c'est le poste sur lequel il ne faut pas passer
de temps.

## 4. Où acheter quoi

Le partage se fait ligne à ligne, pas par principe. Résultat :

| Canal | Lignes | Pourquoi |
|---|---|---|
| LCSC | 68 | moins cher partout ailleurs, souvent d'un facteur 3 à 10 sur les passifs et les discrets |
| Mouser | 3 | l'OPA2810IDR (absent de LCSC), l'ADG1607BCPZ (5,12 contre 5,60 USD estimé) et le FH12-16S (en rupture chez LCSC) |

Deux cas méritent d'être lus avant de valider :

- **La WS2812B n'existe pas chez Mouser** (Worldsemi n'y est pas
  distribué). Un plateau entier en demande 128 : cette ligne seule
  interdit le panier tout Mouser, et c'est l'argument le plus net en
  faveur de la commande chinoise.
- **L'ADG1607 passe chez Mouser pour 0,48 USD par pièce**, sur un prix
  LCSC estimé et non affiché. Si le panier LCSC l'affiche sous 5,12 USD,
  il repasse chez LCSC et le panier Mouser tombe à deux lignes.

## 5. Neuf codes LCSC à corriger avant tout assemblage

La [note 22](notes/22-erreurs-de-conception.md), point 11, avait trouvé
six codes faux sur douze au quadrant 2 x 2. Le contrôle refait ici sur
les cartes du plateau donne ceci :

| Référence | Code du circuit | Code vérifié le 20/09 | Ce que ça change |
|---|---|---|---|
| ADG1607BCPZ | aucun | C209487 | le mux entre enfin dans un ordre d'assemblage |
| AD8421ARZ | C462186 | C392903 | 3,69 USD, 949 en stock |
| ADuM1201ARZ | C123211 | C9669 | 1,28 USD |
| ESP32-S3-WROOM-1-N8 | C2913204 | C2913198 | C2913204 est la variante N8R2 (2 Mo de PSRAM), pas celle du circuit |
| LP2985AIM5-5.0 | C129541 | C109382 | 0,165 USD |
| STM32G474RET6 | C528140 | C521608 | C528140 ne résout pas |
| TPS62130RGTR | C74016 | C43590 | 0,73 USD, 35 283 en stock |
| FH12-16S-0.5SH(55) | C2837584 | C596731 | en rupture, voir le paragraphe 6 |
| OPA2810IDR | C2059830 | aucun chez LCSC | à acheter chez Mouser ou DigiKey |

Le fichier de prix porte le code vérifié, l'outil signale l'écart à
chaque exécution (`lcsc clash`), et c'est ce code qui part dans le
panier. Corriger les générateurs est un autre chantier : regénérer une
carte refait son routage, et celui du quadrant 4 x 4 n'est pas fermé
(note 23, paragraphe 4). Ces codes se corrigent dans
`tools/quadgen/circuit.py` et `tools/boardgen/` à la prochaine reprise du
routage, pas avant.

## 6. Trois risques d'approvisionnement

1. **Le FH12-16S-0.5SH(55) est obsolète.** DigiKey l'annonce comme non
   fabriqué, LCSC est en rupture sur C596731. Le plateau en demande huit
   (quatre côté quadrants, quatre côté cerveau). Un FPC 16 voies au pas
   de 0,5 mm du commerce courant coûte 0,10 à 0,30 USD contre 1,54 :
   changer d'embase économise une dizaine d'USD et supprime le risque,
   au prix d'une vérification d'empreinte sur les deux cartes.
2. **L'OPA2810 n'est pas chez LCSC.** Une commande d'assemblage JLCPCB
   ne pourra pas le poser : soit il est fourni en pièces consignées
   (3 USD de frais par référence étendue, plus la logistique), soit
   l'étage est revu (paragraphe 7).
3. **La variante d'ESP32 diverge.** Le circuit demande un N8, son code
   pointe un N8R2. Les deux existent, le second a 2 Mo de PSRAM en plus ;
   il faut choisir, le firmware ESP-IDF n'en dépend pas aujourd'hui.

## 7. Quatre leviers, chiffrés

| Levier | Ce qu'il rapporte | Ce qu'il coûte en décision |
|---|---|---|
| Frontal single-ended plutôt que différentiel vrai | le poste mux passe de 46 à 12 ou 22 USD selon le composant, soit 24 à 34 USD | la mesure qui tranche reste à définir ([note 16](notes/16-cout-des-cartes.md), section 2) |
| Un double AOP moins cher que l'OPA2810 | de 49 à 18 ou 22 USD, soit environ 28 USD | revue du gabarit (bruit, bande, entrée FET) ; la bande de mesure est de 217 à 613 kHz pour un composant à 70 MHz |
| Embase FPC courante à la place du FH12 | environ 9 USD | vérifier l'empreinte sur le quadrant et sur le cerveau |
| Acheter au compte exact, sans rechange | 31,66 USD | trois semaines d'attente si une pièce meurt au montage ; déconseillé |

Les trois premiers leviers pris ensemble font tomber le panier de 180 à
environ 110 USD, soit un tiers. Aucun ne se décide dans cette fiche :
les deux premiers sont des choix de conception, le troisième une
vérification d'empreinte.

Le levier qui n'est pas dans ce tableau est l'assemblage : la
[note 23](notes/23-commande-jlcpcb.md), paragraphe 8.3, chiffre
l'assemblage économique de quatre quadrants et d'un cerveau à 430 à
480 EUR contre 300 à 350 EUR en cartes nues. Les 130 EUR d'écart
achètent 1 399 poses, dont huit LFCSP au pas de 0,5 mm et un LQFP-64 :
c'est le meilleur rapport de cette fiche, à condition d'avoir corrigé
les codes du paragraphe 5.

## 8. Le plateau complet, cartes comprises

| Poste | EUR TTC | Source |
|---|---|---|
| Composants, panier panaché avec rechange | 199 | cette fiche, paragraphe 2 |
| 5 quadrants 4 x 4 nus, 4 couches, ENIG, cuivre interne 1 oz | 60 à 96 | note 23, paragraphe 8.1 |
| 5 cerveaux nus, 4 couches, ENIG | 34 à 42 | note 23, paragraphe 8.1 |
| Port et TVA sur les cartes | 30 à 48 | note 23, paragraphe 8.1 |
| Port LCSC et Mouser | 25 à 40 | estimé, deux expéditions |
| **Total, tout à souder soi même** | **348 à 425** | |

La commande d'assemblage remplace le port des composants et une partie
du temps de fer par 130 EUR environ, ce qui amène le plateau assemblé
aux alentours de 450 à 500 EUR TTC, cohérent avec la note 23.

## 9. La commande, dans l'ordre

1. **Ne pas commander les cartes du plateau aujourd'hui.** Le quadrant
   4 x 4 n'a pas d'archive de fabrication (47 nets ouverts, note 23,
   paragraphe 4) ; le cerveau en a une, vérifiée. La validation du
   frontal passe d'abord par le quadrant 2 x 2 et la carte de banc, qui
   se commandent tels quels.
2. Rejouer la liste et les paniers (paragraphe 1), pour partir des
   fichiers à jour.
3. Ouvrir le panier LCSC, importer `docs/panier-lcsc.csv`, **relever les
   prix et les stocks réels ligne à ligne** : 63 des 71 lignes sont
   estimées et 8 seulement relevées, notamment tous les passifs. Compléter les codes des passifs
   génériques dans le panier, ou les laisser à la bibliothèque de
   l'assembleur si l'assemblage est retenu.
4. Ouvrir le panier Mouser, importer `docs/panier-mouser.csv`, vérifier
   que l'OPA2810 et l'ADG1607 sont en stock, et arbitrer l'ADG1607 selon
   le prix LCSC affiché (paragraphe 4).
5. Reporter les prix relevés dans `docs/prix-plateau.csv` avec leur
   statut et leur source, rejouer l'outil : le total devient un devis.
6. Pour les cartes, suivre la [note 23](notes/23-commande-jlcpcb.md),
   paragraphes 3 et 7 (empreintes, options, cuivre interne, quatre
   approbations séparées du skill `operate-jlcpcb-order`).
7. Noter dans le [journal](notes/09-journal.md) la date, les prix
   obtenus et les écarts avec cette fiche.

## 10. Sources des relevés du 20/09/2026

- ADG1607BCPZ : [LCSC C209487](https://lcsc.com/product-detail/Analog-Switches_Analog-Devices_ADG1607BCPZ-REEL7_Analog-Devices-ADI-ADG1607BCPZ-REEL7_C209487.html),
  [Octopart](https://octopart.com/adg1607bcpz-reel7-analog+devices-13130399),
  [Mouser](https://www.mouser.com/ProductDetail/Analog-Devices/ADG1607BCPZ-REEL7?qs=BpaRKvA4VqEg%2FkzeF3lydg%3D%3D)
- AD8421ARZ : [LCSC C392903](https://www.lcsc.com/product-detail/Instrumentation-Amplifiers_Analog-Devices-AD8421ARZ-R7_C392903.html),
  [Mouser](https://www.mouser.com/ProductDetail/Analog-Devices/AD8421ARZ?qs=/tpEQrCGXCyoA2YFZOY76g%3D%3D)
- OPA2810IDR : [DigiKey](https://www.digikey.com/en/products/detail/texas-instruments/OPA2810IDR/10715569),
  absent des résultats LCSC
- STM32G474RET6 : [LCSC C521608](https://www.lcsc.com/product-detail/C521608.html),
  [Mouser](https://www.mouser.com/ProductDetail/STMicroelectronics/STM32G474RET6?qs=PzGy0jfpSMvUBs7PMTDqlg%3D%3D)
- ESP32-S3-WROOM-1 : [N8 C2913198](https://lcsc.com/product-detail/WiFi-Modules_Espressif-Systems-ESP32-S3-WROOM-1-N8_C2913198.html),
  [N8R2 C2913204](https://www.lcsc.com/product-detail/C2913204.html)
- TPS62130RGTR : [LCSC C43590](https://www.lcsc.com/product-detail/DC-DC-Converters_Texas-Instruments_TPS62130RGTR_Texas-Instruments-Texas-Instruments-TPS62130RGTR_C43590.html)
- WS2812B : [LCSC C2761795](https://www.lcsc.com/product-detail/Light-Emitting-Diodes-LED_Worldsemi-WS2812B-B-T_C2761795.html)
- AO3400A : [LCSC C20917](https://www.lcsc.com/product-detail/MOSFET_AOS_AO3400A_AO3400A_C20917.html)
- FH12-16S-0.5SH(55) : [LCSC C596731](https://lcsc.com/product-detail/FFC-FPC-Connectors_HRS-Hirose-FH12-16S-0-5SH-55_C596731.html),
  [DigiKey, obsolète](https://www.digikey.com/en/products/detail/hirose-electric-co-ltd/FH12-16S-0-5SH-55/1110319)
- ADuM1201ARZ et LP2985A : relevés du 30/08/2026, [fiche de la maquette](bom-maquette.md)

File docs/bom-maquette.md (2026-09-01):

# Fiche d'approvisionnement de la maquette 2 x 2

Prix relevés le 30/08/2026 par recherche web, chaque ligne porte son
statut : « vérifié » (prix affiché par le distributeur à cette date,
source en bas de page) ou « estimé » (fourchette de marché, à
confirmer au panier). Conversion retenue : 1 USD = 0,92 EUR, arrondie.
Les prix Europe s'entendent TTC pour un particulier en France (TVA
20 %) ; les prix Asie (LCSC, JLCPCB, AliExpress) sont facturés hors
taxe puis la TVA est collectée à la commande (IOSS) ou à l'import,
elle est incluse dans les totaux comparés. La BOM détaillée de la
carte analogique (138 composants) est générée dans
`hardware/mockup-2x2/analog-board/bom.csv` et ses fichiers JLCPCB
(`jlc-bom.csv`, `jlc-cpl.csv`) ; ce document compare les canaux
d'achat, la BOM générée reste la source de vérité des références.

## Comparatif Europe contre Asie, poste par poste

### Circuits intégrés de la carte analogique

| Poste | Référence | Qté | Europe (unitaire) | Asie (unitaire) | Choix conseillé |
|---|---|---|---|---|---|
| Ampli d'instrumentation | AD8421ARZ (R7) | 2 | 8,91 USD Mouser, 9,06 USD DigiKey, 5 361 en stock, vérifié | 3,69 USD LCSC C392903, en stock, vérifié | Asie : moitié prix, à mettre dans la commande JLCPCB |
| Isolateur UART | ADuM1201ARZ-RL7 | 2 | rupture DigiKey (réassort sur commande), vérifié | 1,28 à 1,77 USD LCSC C9669, plus de 11 000 en stock, vérifié | Asie : moins cher et disponible |
| Mux différentiel | 74HCT4052PW,118 | 2 | ~0,60 EUR (estimé) | 0,151 USD LCSC C87681, 33 970 en stock, vérifié | Asie |
| LDO | LP2985A-50DBVR | 2 | ~0,60 EUR (estimé) | 0,165 USD LCSC C109382, 12 375 en stock, vérifié | Asie |
| Buck | TPS62150RGTR | 2 | ~2,50 EUR DigiKey (fourchette Octopart 0,81 à 6,64 USD), estimé | LCSC C527690, 2 003 en stock, prix non affiché (~1,2 USD estimé) | Asie, vérifier le prix au panier |
| Double AOP | OPA2810IDR | 4 | 5,48 USD DigiKey, vérifié | non confirmé chez LCSC | Selon panier : si absent de LCSC, prendre chez Mouser avec la Nucleo |

Lecture : sur les actifs, l'Asie gagne presque partout (souvent de
moitié), et l'assemblage JLCPCB les pose directement, donc le bon
réflexe est de tout mettre dans la commande d'assemblage. L'OPA2810
est le seul candidat à un achat européen d'appoint.

### Cartes (fabrication et assemblage)

| Poste | Europe | Asie | Choix conseillé |
|---|---|---|---|
| Carte bobines 4 couches 100 x 100, 5 pièces dont 2 assemblées (8 LED + 8 condensateurs) | ~60 à 90 EUR fabrication seule (Aisler, Eurocircuits, estimé) | 2 à 5 USD en promotion plus assemblage économique (~10 à 15 USD) et port, vérifié pour les règles | Asie, sans hésiter |
| Carte analogique 2 couches, 5 pièces dont 2 assemblées | assemblage prototype européen : plusieurs centaines d'EUR, estimé | fabrication ~2 USD ; assemblage économique : minimum 0,48 USD par carte plus préparation (~8 USD), chargeurs de bande, rayons X pour le QFN du buck ; composants au forfait ; ~35 à 55 USD le tout, vérifié pour les règles, estimé pour le total | Asie : l'assemblage économique JLCPCB est sans équivalent européen à ce budget |
| Port et taxes JLCPCB vers la France | | ~15 à 20 EUR port, TVA 20 % collectée IOSS | inclus dans les totaux |

### MCU et alimentation

| Poste | Référence | Europe | Asie | Choix conseillé |
|---|---|---|---|---|
| Carte Nucleo | NUCLEO-G474RE | ~17,50 EUR HT RS (15,02 GBP, réassort 27/08/2026), eStore ST en stock (~17 EUR HT), vérifié | revendeurs eBay et AliExpress ~29 EUR, vérifié | Europe : moins cher ET plus sûr (eStore ST ou RS), contre-exemple utile |
| Bloc 12 V 2 A jack 5,5 x 2,1 | | ~10 EUR Amazon ou magasin local, estimé | ~5 EUR AliExpress, estimé | Europe : la sécurité d'une alim secteur CE vaut les 5 EUR |
| Nappes Dupont F-F 20 cm x 20 | | ~3 EUR Amazon, estimé | ~1,50 EUR AliExpress, estimé | indifférent, grouper avec une autre commande |

### Résonateurs de test et bobinage

| Poste | Référence | Qté | Europe | Asie | Choix conseillé |
|---|---|---|---|---|---|
| C0G 1 % 1206 : 6,8, 8,2, 10, 12 nF | ex. Murata GRM31 ou Samsung | 5 de chaque | 0,30 à 0,60 EUR pièce Mouser, estimé (~9 EUR le lot) | 0,03 à 0,10 USD pièce LCSC, estimé (~1,50 EUR le lot) | Asie, à joindre à la commande LCSC ou JLCPCB |
| Fil émaillé 0,25 mm (et 0,315 mm) | 100 g par diamètre | 2 bobines | dès 4,90 EUR pièce (E44, RadioElec 150 m), vérifié pour l'ordre de prix | ~2 à 4 EUR AliExpress, estimé, 3 à 5 semaines | Europe : E44 ou RadioElec, qualité d'émail connue pour un prix proche |
| Fil de Litz 20 x 0,05 (option si Q insuffisant) | | 10 m | ~8 EUR, estimé | ~4 EUR AliExpress, estimé | Asie si commandé d'avance, sinon Europe |

### Aimants

| Poste | Référence | Qté | Europe | Asie | Choix conseillé |
|---|---|---|---|---|---|
| Ferrite Y30 o15 x 4 (pions) | disque axial | 4 + rechange | 1,95 EUR pièce en 15 x 5 Y35 (Magnetpartner), vérifié ; équivalents chez supermagnete, ct-magnet, univers-magnetique | lots AliExpress ~2 à 5 EUR les 10 à 20, estimé, quantité et nuance moins garanties | Europe : la nuance (Y30 contre Y35) et les cotes sont fiables, c'est le paramètre pivot du projet |
| Ferrite Y30 o12 x 4 (variante) | disque axial | 4 | ~1,50 EUR pièce, estimé | idem ci-dessus | Europe |
| N42 o15 x 5 nickelé (chariot, mesure 7) | supermagnete S-15-05-N, exactement la référence du yaml | 2 | ~1,50 à 2 EUR pièce, page produit confirmée N42, prix au panier | lots AliExpress N42 annoncé, nuance invérifiable | Europe : supermagnete, la nuance N42 est garantie |

Les poches des pucks se régénèrent pour toute taille d'aimant du
commerce : modifier `piece_magnet` dans `config/board.yaml` puis
`python mechanical/build_all.py`.

### LED de camp (ADR 0009)

| Poste | Référence | Qté | Europe | Asie | Choix conseillé |
|---|---|---|---|---|---|
| LED RGB adressable 5050 | WS2812B-B | 8 + rechange | ~0,50 EUR pièce (Mouser, revendeurs), estimé | ~0,05 à 0,10 USD pièce LCSC, estimé | Asie : posées par l'assemblage JLCPCB avec leurs 100 nF |
| Tampon de niveau | SN74AHCT1G125DBVR | 2 | ~0,45 EUR, estimé | ~0,10 USD LCSC C350557 (candidat), estimé | Asie, dans l'assemblage |

### Mécanique (achat local, pas de comparatif utile)

| Poste | Quantité | Prix |
|---|---|---|
| Impression 3D (pucks, gabarits, support, gabarit de perçage) ~90 g PETG | | ~3 EUR, estimé |
| Contreplaqué sec 3 à 6 mm, plaque 120 x 120 (surface de jeu, ADR 0009) | 1 | ~4 EUR, estimé |
| Feutre adhésif 0,5 mm | 1 feuille | ~3 EUR, estimé |
| Visserie M3 (8, 30), écrous, entretoises M3 x 25 | kit | ~6 EUR, estimé |

Le bois remplace l'acrylique (préférence d'aspect) : effet nul sur la
fréquence, voir l'ADR 0009 et la mesure M10 ; percer les points
lumineux avec le gabarit `surface-template` généré par la mécanique.

## Trois totaux comparés (TVA et ports inclus)

| Scénario | Total | Délai typique | Commentaire |
|---|---|---|---|
| Tout Europe | ~210 à 235 EUR | moins d'une semaine | pas d'assemblage abordable : suppose de souder soi-même la carte analogique (138 composants dont un QFN) et les 8 LED de la carte bobines, déconseillé |
| Tout Asie | ~145 à 165 EUR | 2 à 5 semaines | Nucleo plus chère et douteuse en revendeur, nuances d'aimants invérifiables |
| Panaché conseillé | ~160 à 180 EUR | 1 à 3 semaines | voir la répartition ci-dessous |

Répartition du panaché conseillé, en quatre commandes :

1. **JLCPCB** (~75 à 90 EUR TTC port inclus) : les deux cartes,
   l'assemblage économique de 2 cartes analogiques et de 2 cartes
   bobines (LED de camp), tous les actifs posés (AD8421, ADuM1201,
   mux, LDO, buck, tampon LED, WS2812B), plus les C0G des résonateurs
   ajoutés au panier LCSC lié.
2. **eStore ST ou RS** (~25 EUR TTC) : la Nucleo-G474RE.
3. **Mouser ou Farnell** (~30 EUR TTC, seulement si nécessaire) :
   OPA2810IDR si absent du panier LCSC, AD8421 de secours ; franco
   Mouser à 50 EUR, sinon grouper avec la Nucleo chez Farnell.
4. **Europe divers** (~40 à 50 EUR) : aimants (supermagnete ou
   Magnetpartner), fil émaillé (E44 ou RadioElec), alim 12 V,
   mécanique locale.

Le brief visait ~70 EUR pour la seule électronique de maquette : le
panaché y répond (cartes assemblées plus actifs ~70 EUR), le reste est
l'outillage réutilisable (Nucleo, alim, fil, aimants, mécanique).

## Vérification finale au panier (à faire à la commande)

Le réseau de cet environnement de travail bloque les API
distributeurs, les codes LCSC de `jlc-bom.csv` sont donc des candidats
issus des références fabricant : la validation ligne à ligne se fait
dans la prévisualisation JLCPCB en téléversant `jlc-bom.csv` et
`jlc-cpl.csv`, l'outil affiche prix, stock et statut (basic, extended)
réels et propose des substituts. Vérifier aussi l'orientation des
diodes et du régulateur sur le rendu avant de valider. Les prix datés
ci-dessus bougent (les fourchettes constatées sur les actifs vont du
simple au double entre canaux), refaire le total au moment de
commander.

## Sources des prix vérifiés (30/08/2026)

- AD8421ARZ : [Mouser](https://www.mouser.com/ProductDetail/Analog-Devices/AD8421ARZ),
  [DigiKey](https://www.digikey.com/en/products/detail/analog-devices-inc/AD8421ARZ/3340511),
  [LCSC C392903](https://www.lcsc.com/product-detail/Instrumentation-Amplifiers_Analog-Devices-AD8421ARZ-R7_C392903.html)
- ADuM1201ARZ-RL7 : [LCSC C9669](https://www.lcsc.com/product-detail/C9669.html),
  [DigiKey](https://www.digikey.com/en/products/detail/analog-devices-inc/ADUM1201ARZ-RL7/995629)
- 74HCT4052PW : [LCSC C87681](https://www.lcsc.com/product-detail/Analog-Switches_Nexperia-74HCT4052PW-118_C87681.html)
- LP2985A-50DBVR : [LCSC C109382](https://lcsc.com/product-detail/Linear-Voltage-Regulators-LDO_Texas-Instruments-LP2985A-50DBVR_C109382.html)
- TPS62150RGTR : [Octopart](https://octopart.com/tps62150rgtr-texas+instruments-21329326),
  [LCSC C527690](https://www.lcsc.com/product-image/C527690.html)
- OPA2810IDR : [DigiKey](https://www.digikey.com/en/products/detail/texas-instruments/OPA2810IDR/10715569)
- NUCLEO-G474RE : [RS](https://uk.rs-online.com/web/p/microcontroller-development-tools/1939786),
  [eStore ST](https://estore.st.com/en/nucleo-g474re-cpn.html)
- Tarifs JLCPCB : [4 couches](https://jlcpcb.com/blog/special-discount-on-quality-4-layers-pcbs),
  [règles assemblage](https://jlcpcb.com/help/article/pcb-assembly-price)
- Aimants : [Magnetpartner ferrite 15 x 5](https://magnetpartner.com/ferrite-magnets-disc-15x5-mm),
  [supermagnete S-15-05-N](https://www.supermagnete.de/eng/disc-magnets-neodymium/disc-magnet-15mm-5mm_S-15-05-N)
- Fil émaillé : [E44](https://www.e44.com/alimentations/alimentations-tous-types/transformateurs/bobinage/fil-cuivre-emaille/),
  [RadioElec](https://www.radioelec.com/en/enameled-copper-wire-025-mm-coil-150-meters-xml-350_357_459-1409.html)

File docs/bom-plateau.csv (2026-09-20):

Family | Value | Footprint | MPN | LCSC | quadrant | brain | Total | Buy | LCSC_USD | Mouser_USD | Cheapest | Line_USD | Status
ic | ADG1607 | LFCSP-32-1EP_5x5mm_P0.5mm_EP3.1x3.1mm | ADG1607BCPZ | C209487 | 8 | 0 | 8 | 9 | 5.6000 | 5.1200 | mouser | 46.0800 | estimated
ic | OPA2810 | SOIC-8_3.9x4.9mm_P1.27mm | OPA2810IDR |  | 8 | 0 | 8 | 9 |  | 5.4800 | mouser | 49.3200 | verified
ic | 74HC154 | TSSOP-24_4.4x7.8mm_P0.65mm | 74HC154PW | C5613 | 4 | 0 | 4 | 5 | 0.2800 | 0.7500 | lcsc | 1.4000 | estimated
ic | 74HC4514 | TSSOP-24_4.4x7.8mm_P0.65mm | 74HC4514PW | C5615 | 4 | 0 | 4 | 5 | 0.4200 | 1.2000 | lcsc | 2.1000 | estimated
ic | AD8421 | SOIC-8_3.9x4.9mm_P1.27mm | AD8421ARZ | C392903 | 4 | 0 | 4 | 5 | 3.6908 | 8.9100 | lcsc | 18.4540 | verified
ic | 74LVC1G04 | SOT-23-5 | SN74LVC1G04DBVR | C7477 | 4 | 0 | 4 | 5 | 0.0400 | 0.4500 | lcsc | 0.2000 | estimated
ic | ADuM1201 | SOIC-8_3.9x4.9mm_P1.27mm | ADuM1201ARZ | C9669 | 0 | 1 | 1 | 2 | 1.2800 | 3.5000 | lcsc | 2.5600 | verified
ic | AMS1117-3.3 | SOT-223-3_TabPin2 | AMS1117-3.3 | C6186 | 0 | 1 | 1 | 2 | 0.0550 | 0.6000 | lcsc | 0.1100 | estimated
ic | AP2112K-3.3 | SOT-23-5 | AP2112K-3.3TRG1 | C51118 | 0 | 1 | 1 | 2 | 0.0950 | 0.4500 | lcsc | 0.1900 | estimated
ic | ESP32-S3-WROOM-1 | ESP32-S3-WROOM-1 | ESP32-S3-WROOM-1-N8 | C2913198 | 0 | 1 | 1 | 2 | 3.3000 | 3.9000 | lcsc | 6.6000 | estimated
ic | LP2985-5.0 | SOT-23-5 | LP2985AIM5-5.0 | C109382 | 0 | 1 | 1 | 2 | 0.1650 | 1.3000 | lcsc | 0.3300 | verified
ic | 74AHCT1G125 | SOT-23-5 | SN74AHCT1G125DBVR | C350557 | 0 | 1 | 1 | 2 | 0.1000 | 0.5500 | lcsc | 0.2000 | estimated
ic | STM32G474RE | LQFP-64_10x10mm_P0.5mm | STM32G474RET6 | C521608 | 0 | 1 | 1 | 2 | 5.5000 | 10.5000 | lcsc | 11.0000 | estimated
ic | TPS62130 | QFN-16-1EP_3x3mm_P0.5mm_EP1.75x1.75mm | TPS62130RGTR | C43590 | 0 | 1 | 1 | 2 | 0.7323 | 3.6000 | lcsc | 1.4646 | verified
ic | USBLC6-2 | SOT-23-6 | USBLC6-2SC6 | C7519 | 0 | 1 | 1 | 2 | 0.0900 | 0.5500 | lcsc | 0.1800 | estimated
connector | FPC 16 | Hirose_FH12-16S-0.5SH_1x16-1MP_P0.50mm_Horizontal | FH12-16S-0.5SH(55) | C596731 | 4 | 4 | 8 | 9 | 1.5384 | 1.2000 | mouser | 10.8000 | verified
connector | ESP PROG | PinHeader_1x06_P2.54mm_Vertical |  |  | 0 | 1 | 1 | 2 | 0.0300 | 0.4000 | lcsc | 0.0600 | estimated
connector | MOTION | PinHeader_2x10_P2.54mm_Vertical |  |  | 0 | 1 | 1 | 2 | 0.1200 | 1.0000 | lcsc | 0.2400 | estimated
connector | PI ZERO | PinHeader_2x04_P2.54mm_Vertical |  |  | 0 | 1 | 1 | 2 | 0.0500 | 0.4500 | lcsc | 0.1000 | estimated
connector | POWER | PinHeader_2x04_P2.54mm_Vertical |  |  | 0 | 1 | 1 | 2 | 0.0500 | 0.4500 | lcsc | 0.1000 | estimated
connector | SWD | PinHeader_2x05_P1.27mm_Vertical |  |  | 0 | 1 | 1 | 2 | 0.1000 | 0.9000 | lcsc | 0.2000 | estimated
connector | USB-C | USB_C_Receptacle_GCT_USB4085 | USB4085-GF-A | C2988369 | 0 | 1 | 1 | 2 | 0.3500 | 0.9500 | lcsc | 0.7000 | estimated
led | WS2812B | LED_WS2812B_PLCC4_5.0x5.0mm_P3.2mm | WS2812B | C2761795 | 128 | 0 | 128 | 141 | 0.0616 |  | lcsc | 8.6856 | verified
transistor | AO3400A | SOT-23 | AO3400A | C20917 | 68 | 2 | 70 | 77 | 0.0482 | 0.2500 | lcsc | 3.7114 | verified
transistor | AO3401A | SOT-23 | AO3401A | C15127 | 68 | 1 | 69 | 76 | 0.0520 | 0.2800 | lcsc | 3.9520 | estimated
diode | B5819W | D_SOD-123 | B5819W | C8598 | 128 | 0 | 128 | 141 | 0.0130 | 0.3000 | lcsc | 1.8330 | estimated
diode | BAV99W | SOT-323_SC-70 | BAV99W |  | 128 | 0 | 128 | 141 | 0.0150 | 0.1300 | lcsc | 2.1150 | estimated
diode | SS34FL | D_SOD-123F | SS34FL | C2480216 | 64 | 0 | 64 | 71 | 0.0350 | 0.3500 | lcsc | 2.4850 | estimated
diode | BAV99 | SOT-23 | BAV99 | C2500 | 4 | 1 | 5 | 6 | 0.0120 | 0.1200 | lcsc | 0.0720 | estimated
diode | LED | LED_0603_1608Metric | 19-217/GHC-YR1S2/3T | C72043 | 0 | 4 | 4 | 5 | 0.0150 | 0.1500 | lcsc | 0.0750 | estimated
diode | SS34 | D_SMA | SS34 | C8678 | 0 | 1 | 1 | 2 | 0.0350 | 0.3500 | lcsc | 0.0700 | estimated
inductor | 2u2 | L_Bourns_SRN6045TA | SRN6045TA-2R2M | C167219 | 0 | 1 | 1 | 2 | 0.2500 | 0.7500 | lcsc | 0.5000 | estimated
ferrite | BLM21PG221 | R_0805_2012Metric | BLM21PG221SN1D | C18305 | 0 | 1 | 1 | 2 | 0.0300 | 0.2000 | lcsc | 0.0600 | estimated
buzzer | 12 mm | Buzzer_12x9.5RM7.6 |  |  | 0 | 1 | 1 | 2 | 0.3000 | 1.5000 | lcsc | 0.6000 | estimated
switch | BOOT | SW_SPST_PTS645 | PTS645SM43SMTR92 | C221929 | 0 | 5 | 5 | 6 | 0.0600 | 0.3500 | lcsc | 0.3600 | estimated
fuse | 2A | Fuse_1206_3216Metric |  |  | 0 | 2 | 2 | 3 | 0.0500 | 0.3500 | lcsc | 0.1500 | estimated
fuse | 1A | Fuse_1206_3216Metric |  |  | 0 | 1 | 1 | 2 | 0.0500 | 0.3500 | lcsc | 0.1000 | estimated
jumper | COMM_3V3: 1 ESP / 3 PI | PinHeader_1x03_P2.54mm_Vertical |  |  | 0 | 1 | 1 | 2 | 0.0200 | 0.2500 | lcsc | 0.0400 | estimated
capacitor | 100n | C_0603_1608Metric |  |  | 172 | 10 | 182 | 201 | 0.0025 | 0.0150 | lcsc | 0.5025 | estimated
capacitor | 1n | C_0603_1608Metric |  |  | 12 | 4 | 16 | 18 | 0.0200 | 0.1000 | lcsc | 0.3600 | estimated
capacitor | 1u | C_0603_1608Metric |  |  | 8 | 4 | 12 | 14 | 0.0060 | 0.0500 | lcsc | 0.0840 | estimated
capacitor | 330p | C_0603_1608Metric |  |  | 8 | 0 | 8 | 9 | 0.0200 | 0.1000 | lcsc | 0.1800 | estimated
capacitor | 10u/10V | C_1206_3216Metric |  |  | 4 | 3 | 7 | 8 | 0.0180 | 0.2000 | lcsc | 0.1440 | estimated
capacitor | 10u/25V | C_1206_3216Metric |  |  | 4 | 2 | 6 | 7 | 0.0200 | 0.2200 | lcsc | 0.1400 | estimated
capacitor | 10n | C_0603_1608Metric |  |  | 0 | 2 | 2 | 3 | 0.0040 | 0.0400 | lcsc | 0.0120 | estimated
capacitor | 22u/10V | C_1206_3216Metric |  |  | 0 | 2 | 2 | 3 | 0.0300 | 0.3000 | lcsc | 0.0900 | estimated
capacitor | 100u/10V | CP_Elec_6.3x7.7 |  |  | 0 | 1 | 1 | 2 | 0.0600 | 0.4000 | lcsc | 0.1200 | estimated
capacitor | 100u/25V | CP_Elec_6.3x7.7 |  |  | 0 | 1 | 1 | 2 | 0.0700 | 0.4500 | lcsc | 0.1400 | estimated
capacitor | 2u2 | C_0603_1608Metric |  |  | 0 | 1 | 1 | 2 | 0.0080 | 0.0600 | lcsc | 0.0160 | estimated
capacitor | 3n3 | C_0603_1608Metric |  |  | 0 | 1 | 1 | 2 | 0.0200 | 0.1000 | lcsc | 0.0400 | estimated
capacitor | 4u7 | C_0603_1608Metric |  |  | 0 | 1 | 1 | 2 | 0.0100 | 0.0800 | lcsc | 0.0200 | estimated
resistor | 10k | R_0603_1608Metric |  |  | 132 | 6 | 138 | 152 | 0.0015 | 0.0120 | lcsc | 0.2280 | estimated
resistor | 330R | R_0603_1608Metric |  |  | 128 | 0 | 128 | 141 | 0.0015 | 0.0120 | lcsc | 0.2115 | estimated
resistor | 100k | R_0402_1005Metric |  |  | 64 | 0 | 64 | 71 | 0.0012 | 0.0120 | lcsc | 0.0852 | estimated
resistor | 680R | R_0805_2012Metric |  |  | 64 | 0 | 64 | 71 | 0.0025 | 0.0150 | lcsc | 0.1775 | estimated
resistor | 100k | R_0603_1608Metric |  |  | 16 | 6 | 22 | 25 | 0.0015 | 0.0120 | lcsc | 0.0375 | estimated
resistor | 1k | R_0603_1608Metric |  |  | 12 | 4 | 16 | 18 | 0.0015 | 0.0120 | lcsc | 0.0270 | estimated
resistor | 49R9 | R_0603_1608Metric |  |  | 4 | 4 | 8 | 9 | 0.0020 | 0.0140 | lcsc | 0.0180 | estimated
resistor | 590R | R_0603_1608Metric |  |  | 8 | 0 | 8 | 9 | 0.0020 | 0.0140 | lcsc | 0.0180 | estimated
resistor | 750R | R_0603_1608Metric |  |  | 8 | 0 | 8 | 9 | 0.0020 | 0.0140 | lcsc | 0.0180 | estimated
resistor | 787R | R_0603_1608Metric |  |  | 8 | 0 | 8 | 9 | 0.0020 | 0.0140 | lcsc | 0.0180 | estimated
resistor | 470R | R_0603_1608Metric |  |  | 4 | 1 | 5 | 6 | 0.0015 | 0.0120 | lcsc | 0.0090 | estimated
resistor | 10R | R_2010_5025Metric |  |  | 4 | 0 | 4 | 5 | 0.0200 | 0.1500 | lcsc | 0.1000 | estimated
resistor | 20k5 | R_0603_1608Metric |  |  | 4 | 0 | 4 | 5 | 0.0020 | 0.0140 | lcsc | 0.0100 | estimated
resistor | 3.57k | R_0603_1608Metric |  |  | 4 | 0 | 4 | 5 | 0.0020 | 0.0140 | lcsc | 0.0100 | estimated
resistor | 523R | R_0603_1608Metric |  |  | 4 | 0 | 4 | 5 | 0.0020 | 0.0140 | lcsc | 0.0100 | estimated
resistor | 0R | R_0603_1608Metric |  |  | 0 | 3 | 3 | 4 | 0.0012 | 0.0100 | lcsc | 0.0048 | estimated
resistor | 22R | R_0603_1608Metric |  |  | 0 | 2 | 2 | 3 | 0.0015 | 0.0120 | lcsc | 0.0045 | estimated
resistor | 4k7 | R_0603_1608Metric |  |  | 0 | 2 | 2 | 3 | 0.0015 | 0.0120 | lcsc | 0.0045 | estimated
resistor | 5k1 | R_0603_1608Metric |  |  | 0 | 2 | 2 | 3 | 0.0015 | 0.0120 | lcsc | 0.0045 | estimated
resistor | 523k | R_0603_1608Metric |  |  | 0 | 1 | 1 | 2 | 0.0020 | 0.0140 | lcsc | 0.0040 | estimated

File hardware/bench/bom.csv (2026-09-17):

References | Qty | Value | Footprint | MPN | LCSC | DNP
C1 | 1 | 100u/25V | CP_Elec_6.3x7.7
C10 | 1 | 10u/10V | C_1206_3216Metric
C13 | 1 | 1n | C_0603_1608Metric
C2 | 1 | 10u/25V | C_1206_3216Metric
C11 C12 C14 C3 | 4 | 100n | C_0603_1608Metric
C4 | 1 | 3n3 | C_0603_1608Metric
C5 C6 | 2 | 22u/10V | C_1206_3216Metric
C7 | 1 | 100u/10V | CP_Elec_6.3x7.7
C8 | 1 | 10n | C_0603_1608Metric
C9 | 1 | 2u2 | C_0603_1608Metric
D1 | 1 | SS34 | D_SMA | SS34 | C8678
D2 | 1 | SMBJ15A | D_SMB | SMBJ15A | C113962
F1 | 1 | 1A | Fuse_1206_3216Metric
F2 | 1 | 2A | Fuse_1206_3216Metric
FB1 | 1 | BLM21PG221 | R_0805_2012Metric | BLM21PG221SN1D | C18305
J1 | 1 | 12V | BarrelJack_Horizontal | DC-005-5.5x2.1 | C381118
J2 | 1 | QUADRANT | Hirose_FH12-16S-0.5SH_1x16-1MP_P0.50mm_Horizontal | FH12-16S-0.5SH(55) | C2837584
J3 | 1 | POWER | PinHeader_1x08_P2.54mm_Vertical
J4 | 1 | ANALOG | PinHeader_1x06_P2.54mm_Vertical
J5 | 1 | DIGITAL 0-7 | PinHeader_1x08_P2.54mm_Vertical
J6 | 1 | DIGITAL 8-15 | PinHeader_1x10_P2.54mm_Vertical
JP1 | 1 | 5VA: 1 LDO / 3 BUCK | PinHeader_1x03_P2.54mm_Vertical
L1 | 1 | 2u2 | L_Bourns_SRN6045TA | SRN6045TA-2R2M | C167219
R1 R2 R4 | 3 | 100k | R_0603_1608Metric
R3 | 1 | 523k | R_0603_1608Metric
R5 | 1 | 470R | R_0603_1608Metric
R6 | 1 | 49R9 | R_0603_1608Metric
TP1 | 1 | LED_END | TestPoint_Pad_1.5x1.5mm
TP2 | 1 | 5VA | TestPoint_Pad_1.5x1.5mm
TP3 | 1 | 5V | TestPoint_Pad_1.5x1.5mm
TP4 | 1 | 3V3 | TestPoint_Pad_1.5x1.5mm
TP5 | 1 | GND | TestPoint_Pad_1.5x1.5mm
TP6 | 1 | VIN | TestPoint_Pad_1.5x1.5mm
TP7 | 1 | ADC1 | TestPoint_Pad_1.5x1.5mm
U1 | 1 | TPS62130 | QFN-16-1EP_3x3mm_P0.5mm_EP1.75x1.75mm | TPS62130RGTR | C74016
U2 | 1 | LP2985-5.0 | SOT-23-5 | LP2985AIM5-5.0 | C129541
U3 | 1 | 74AHCT1G125 | SOT-23-5 | SN74AHCT1G125DBVR | C350557

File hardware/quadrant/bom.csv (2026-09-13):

References | Qty | Value | Footprint | MPN | LCSC | DNP
C1 | 1 | 10u/25V | C_1206_3216Metric
C13 C23 | 2 | 1u | C_0603_1608Metric
C17 C18 C24 | 3 | 1n | C_0603_1608Metric
C19 C20 | 2 | 330p | C_0603_1608Metric
C2 | 1 | 10u/10V | C_1206_3216Metric
C14 C15 C16 C21 C22 C3 C4 C5 C6 C7 C8 CL1 CL10 CL11 CL12 CL13 CL14 CL15 CL16 CL17 CL18 CL19 CL2 CL20 CL21 CL22 CL23 CL24 CL25 CL26 CL27 CL28 CL29 CL3 CL30 CL31 CL32 CL4 CL5 CL6 CL7 CL8 CL9 | 43 | 100n | C_0603_1608Metric
D111 D112 D121 D122 D131 D132 D141 D142 D151 D152 D161 D162 D171 D172 D181 D182 D191 D192 D201 D202 D211 D212 D221 D222 D231 D232 D241 D242 D251 D252 D261 D262 | 32 | BAV99W | SOT-323_SC-70 | BAV99W
D113 D115 D123 D125 D133 D135 D143 D145 D153 D155 D163 D165 D173 D175 D183 D185 D193 D195 D203 D205 D213 D215 D223 D225 D233 D235 D243 D245 D253 D255 D263 D265 | 32 | B5819W | D_SOD-123 | B5819W | C8598
D114 D124 D134 D144 D154 D164 D174 D184 D194 D204 D214 D224 D234 D244 D254 D264 | 16 | SS34FL | D_SOD-123F | SS34FL | C2480216
D3 | 1 | BAV99 | SOT-23 | BAV99 | C2500
J1 | 1 | FPC 16 | Hirose_FH12-16S-0.5SH_1x16-1MP_P0.50mm_Horizontal | FH12-16S-0.5SH(55) | C2837584
LD1 LD10 LD11 LD12 LD13 LD14 LD15 LD16 LD17 LD18 LD19 LD2 LD20 LD21 LD22 LD23 LD24 LD25 LD26 LD27 LD28 LD29 LD3 LD30 LD31 LD32 LD4 LD5 LD6 LD7 LD8 LD9 | 32 | WS2812B | LED_WS2812B_PLCC4_5.0x5.0mm_P3.2mm | WS2812B | C2761795
NT1 | 1 | spirale C1 | COIL_TIE
NT10 | 1 | spirale C10 | COIL_TIE
NT11 | 1 | spirale C11 | COIL_TIE
NT12 | 1 | spirale C12 | COIL_TIE
NT13 | 1 | spirale C13 | COIL_TIE
NT14 | 1 | spirale C14 | COIL_TIE
NT15 | 1 | spirale C15 | COIL_TIE
NT16 | 1 | spirale C16 | COIL_TIE
NT2 | 1 | spirale C2 | COIL_TIE
NT3 | 1 | spirale C3 | COIL_TIE
NT4 | 1 | spirale C4 | COIL_TIE
NT5 | 1 | spirale C5 | COIL_TIE
NT6 | 1 | spirale C6 | COIL_TIE
NT7 | 1 | spirale C7 | COIL_TIE
NT8 | 1 | spirale C8 | COIL_TIE
NT9 | 1 | spirale C9 | COIL_TIE
Q1 Q112 Q122 Q132 Q142 Q152 Q162 Q172 Q182 Q192 Q202 Q212 Q222 Q232 Q242 Q252 Q262 | 17 | AO3401A | SOT-23 | AO3401A | C15127
Q111 Q121 Q131 Q141 Q151 Q161 Q171 Q181 Q191 Q2 Q201 Q211 Q221 Q231 Q241 Q251 Q261 | 17 | AO3400A | SOT-23 | AO3400A | C20917
R113 R114 R123 R124 R133 R134 R143 R144 R153 R154 R163 R164 R173 R174 R183 R184 R193 R194 R203 R204 R213 R214 R223 R224 R233 R234 R243 R244 R253 R254 R263 R264 | 32 | 330R | R_0603_1608Metric
R115 R125 R135 R145 R155 R165 R175 R185 R195 R205 R215 R225 R235 R245 R255 R265 | 16 | 100k | R_0402_1005Metric
R116 R126 R136 R146 R156 R166 R176 R186 R196 R206 R216 R226 R236 R246 R256 R266 | 16 | 680R | R_0805_2012Metric
R14 | 1 | 523R | R_0603_1608Metric
R15 R16 | 2 | 787R | R_0603_1608Metric
R17 R21 | 2 | 590R | R_0603_1608Metric
R18 R22 R24 | 3 | 1k | R_0603_1608Metric
R19 R20 | 2 | 750R | R_0603_1608Metric
R23 | 1 | 3.57k | R_0603_1608Metric
R25 | 1 | 49R9 | R_0603_1608Metric
R5 | 1 | 20k5 | R_0603_1608Metric
R111 R112 R121 R122 R131 R132 R141 R142 R151 R152 R161 R162 R171 R172 R181 R182 R191 R192 R201 R202 R211 R212 R221 R222 R231 R232 R241 R242 R251 R252 R261 R262 R6 | 33 | 10k | R_0603_1608Metric
R7 | 1 | 470R | R_0603_1608Metric
R10 R12 R13 R8 | 4 | 100k | R_0603_1608Metric
R9 | 1 | 10R | R_2010_5025Metric
TP1 | 1 | AMP_OUT | TestPoint_Pad_1.5x1.5mm
TP2 | 1 | VREF | TestPoint_Pad_1.5x1.5mm
TP3 | 1 | DRIVE_BUS | TestPoint_Pad_1.5x1.5mm
TP4 | 1 | GND | TestPoint_Pad_1.5x1.5mm
U1 | 1 | 74HC4514 | TSSOP-24_4.4x7.8mm_P0.65mm | 74HC4514PW | C5615
U2 | 1 | 74HC154 | TSSOP-24_4.4x7.8mm_P0.65mm | 74HC154PW | C5613
U3 U4 | 2 | ADG1607 | LFCSP-32-1EP_5x5mm_P0.5mm_EP3.1x3.1mm | ADG1607BCPZ
U5 | 1 | AD8421 | SOIC-8_3.9x4.9mm_P1.27mm | AD8421ARZ | C462186
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

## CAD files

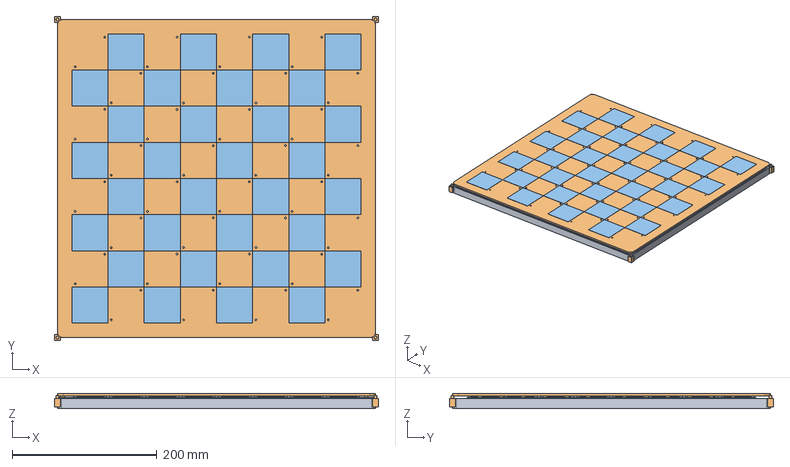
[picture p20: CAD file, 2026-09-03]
mechanical/exports/plateau-fin-assemblage.step
448.0 x 448.0 x 20.9 mm

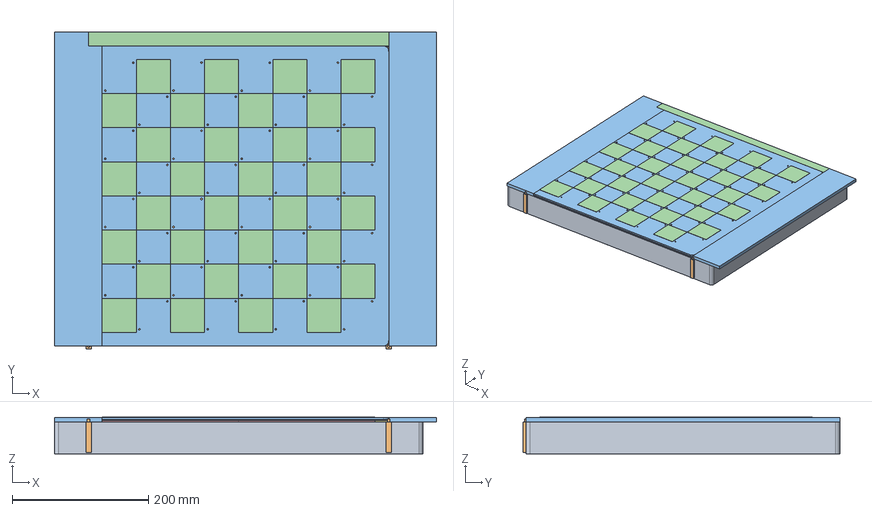
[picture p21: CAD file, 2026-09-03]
mechanical/exports/plateau-chariot-assemblage.step
560.0 x 464.0 x 53.9 mm

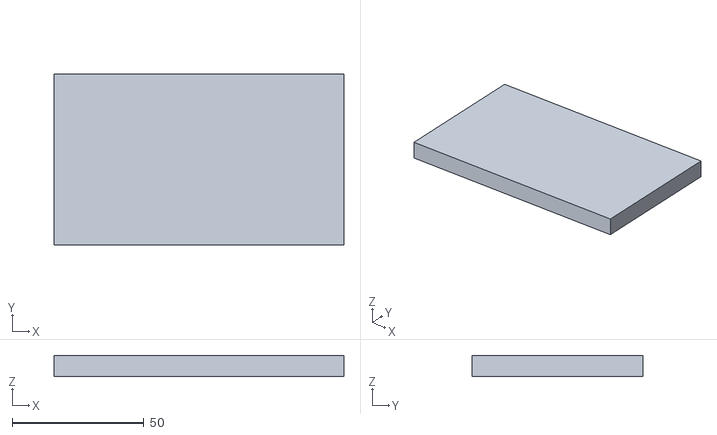
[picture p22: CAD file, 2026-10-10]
media/pitch/commun/meshes/fin-cellule-3-7c8994.stl
110.0 x 65.0 x 8.00

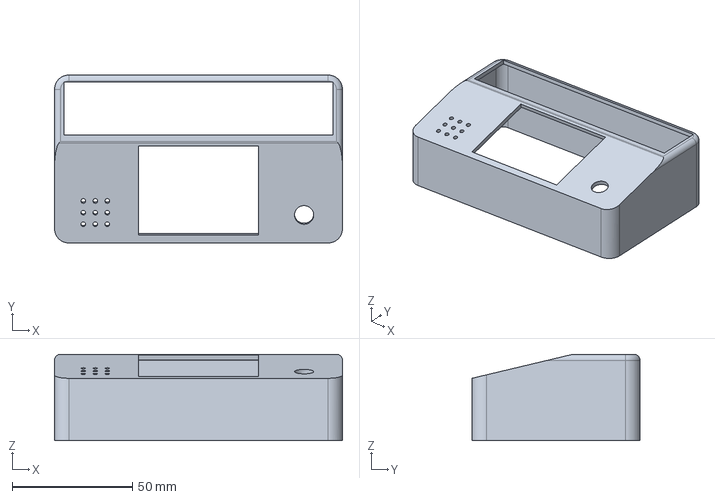
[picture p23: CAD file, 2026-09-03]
mechanical/exports/horloge-boitier.step
120.0 x 70.0 x 36.0 mm

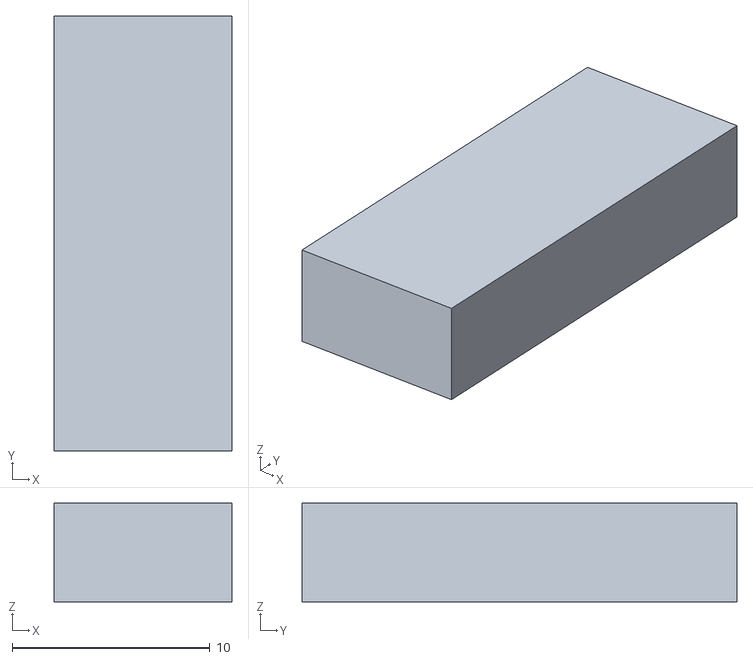
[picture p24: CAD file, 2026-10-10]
media/pitch/commun/meshes/fin-quadrant-2-e6e1d6.stl
9.00 x 22.0 x 5.00

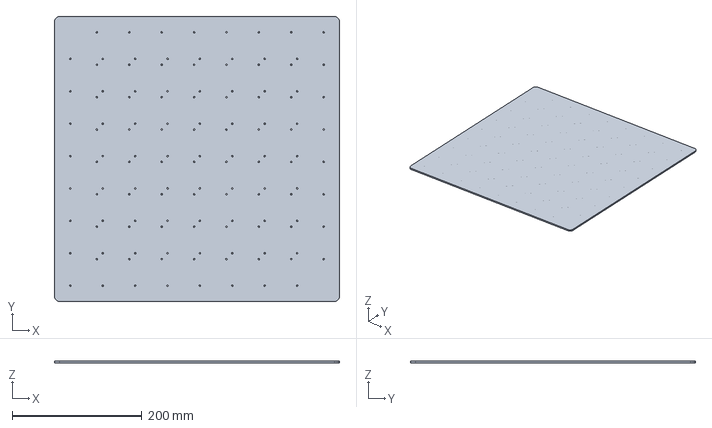
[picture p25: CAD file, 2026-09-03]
mechanical/exports/plateau-contreplaque.step
440.0 x 440.0 x 3.00 mm

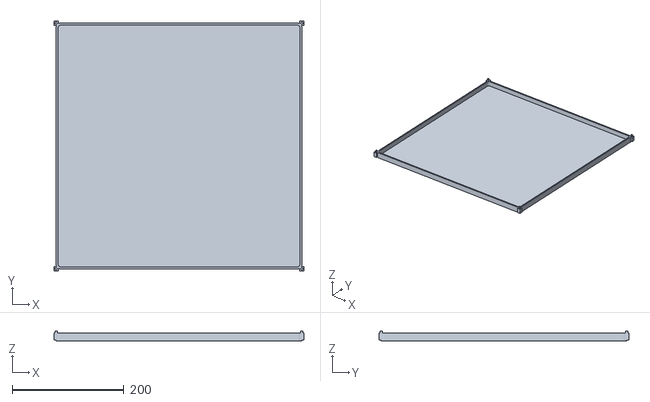
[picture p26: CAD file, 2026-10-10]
media/pitch/commun/meshes/fin-base-3b414a.stl
448.0 x 448.0 x 18.0

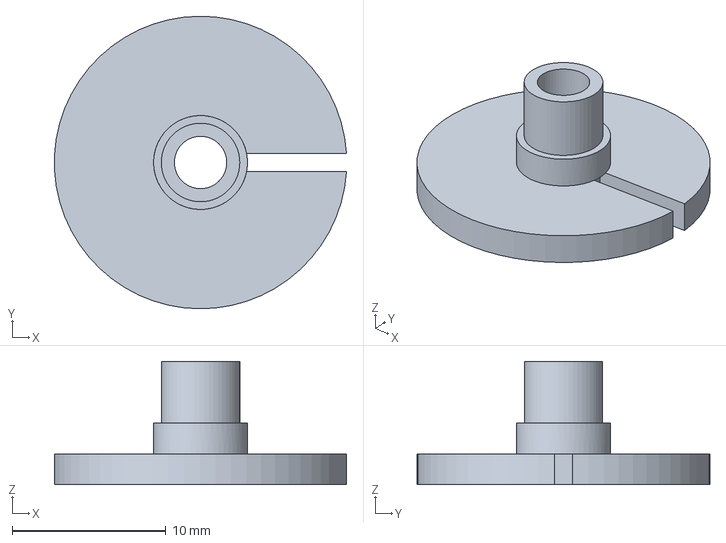
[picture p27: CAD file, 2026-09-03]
mechanical/exports/jig-core-d16.step
19.0 x 19.0 x 8.00 mm

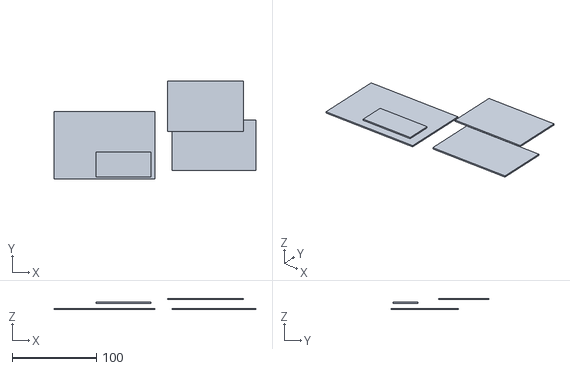
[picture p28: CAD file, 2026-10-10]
media/pitch/commun/meshes/chariot-base-2f3b2a.stl
240.0 x 116.0 x 13.6

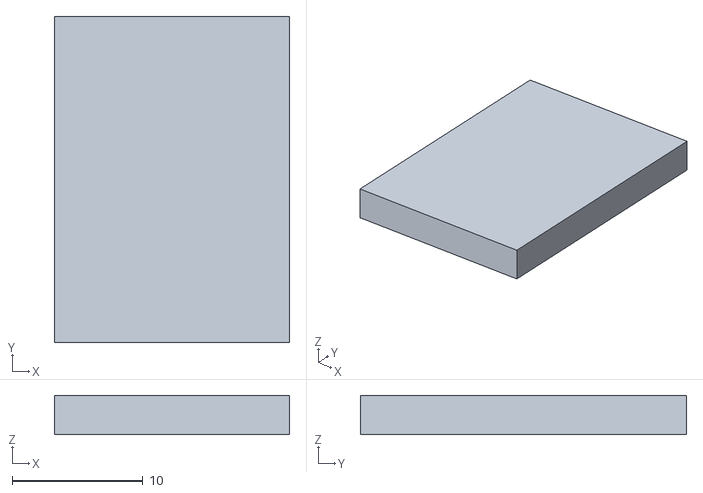
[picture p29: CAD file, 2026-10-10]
media/pitch/commun/meshes/fin-cartes-8aa1b5.stl
18.0 x 25.0 x 3.00

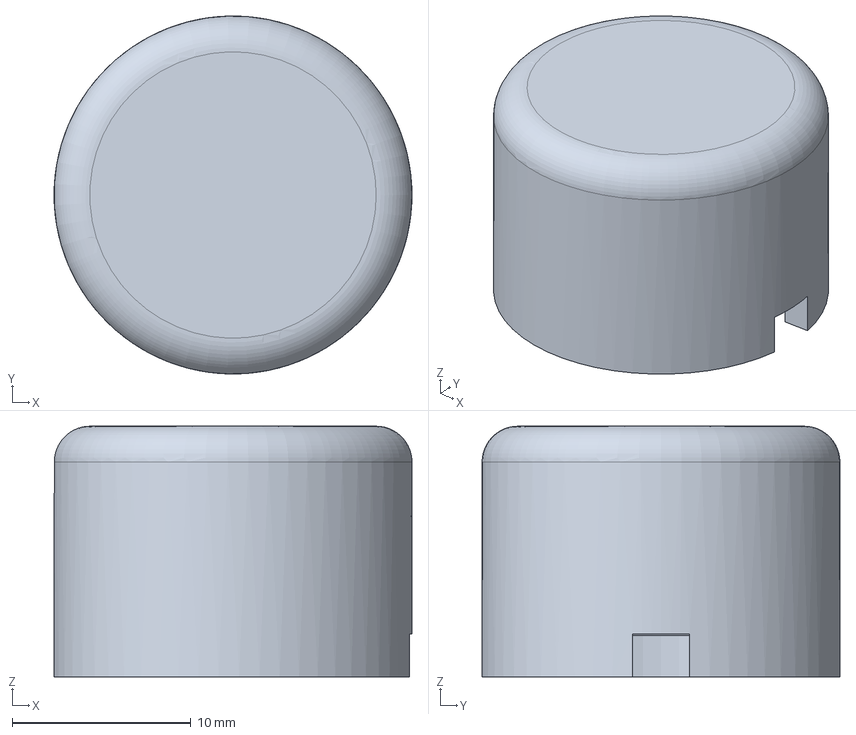
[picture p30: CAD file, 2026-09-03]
mechanical/exports/puck-knight-black.step
20.0 x 20.0 x 14.0 mm

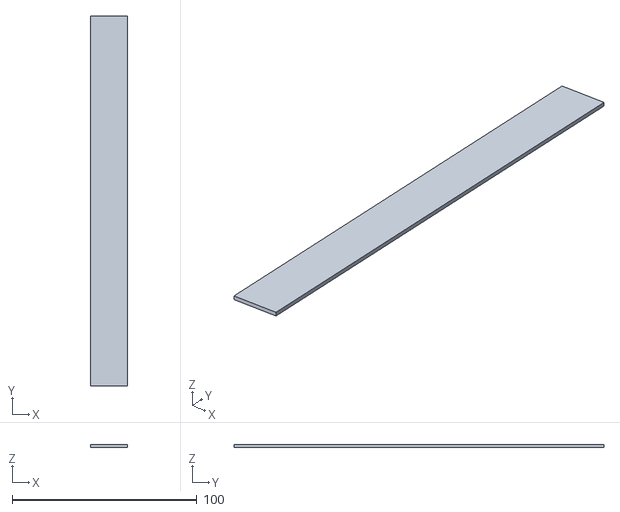
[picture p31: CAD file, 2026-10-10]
media/pitch/commun/meshes/fin-quadrant-4-2f3b2a.stl
20.0 x 200.0 x 1.60

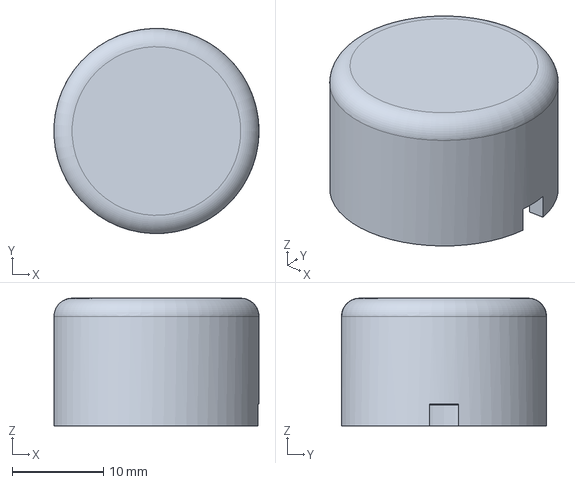
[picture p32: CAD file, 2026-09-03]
mechanical/exports/puck-rook-black.step
22.5 x 22.5 x 14.0 mm

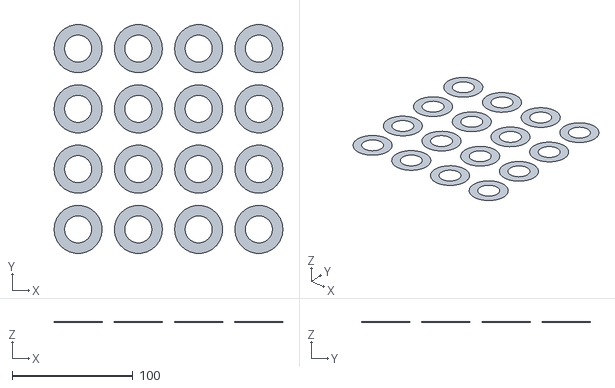
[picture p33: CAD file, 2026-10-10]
media/pitch/commun/meshes/fin-quadrant-4-d38a3c.stl
190.0 x 189.7 x 0.2

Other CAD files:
media/pitch/commun/meshes/fin-quadrant-4-e6e1d6.stl
mechanical/exports/magnet-cup.step
media/pitch/commun/meshes/chariot-base-9da5ad.stl
media/pitch/commun/meshes/chariot-base-22262b.stl
mechanical/exports/horloge-barre.step
mechanical/exports/horloge-barre.stl
mechanical/exports/horloge-boitier.stl
mechanical/exports/horloge-fond.step
mechanical/exports/jig-core-d13.5.step
mechanical/exports/jig-core-d13.5.stl
mechanical/exports/jig-core-d16.stl
mechanical/exports/jig-core-d18.5.step
mechanical/exports/jig-core-d18.5.stl
mechanical/exports/jig-washer-d13.5.step
mechanical/exports/jig-washer-d13.5.stl
mechanical/exports/jig-washer-d16.step
mechanical/exports/jig-washer-d16.stl
mechanical/exports/jig-washer-d18.5.step
mechanical/exports/jig-washer-d18.5.stl
mechanical/exports/magnet-bracket-base.step
mechanical/exports/magnet-bracket-base.stl
mechanical/exports/magnet-cup.stl
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

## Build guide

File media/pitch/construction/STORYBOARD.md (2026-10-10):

---
format: 1080x1920
duration: 54.5s
message: "Couche par couche, ce qu'il y a sous le bois"
arc: "démontage → titre → base, énergie, cerveau, quadrants, bois → une pièce → les pièces → fini → base chariot → fin"
audience: "financement participatif, Instagram et TikTok"
mode: collaborative
---

Fil conducteur : une seule caméra qui tourne lentement autour du
plateau, et chaque couche, vrai solide CadQuery, qui tombe d'en haut et
se pose avec un bruit sourd. Plan tenu : le plateau fini (10). Les
chiffres entre accolades sont des clés de `assets/facts.js`. Toute la
scène 3D vit dans `index.html` ; les plans ci-dessous sont des fenêtres
de temps de cette scène et de `compositions/textes.html`.

## Frame 1 : Accroche

- status: animated
- src: index.html (0 à 3 s) et compositions/textes.html
- duration: 3s
- transition_in: cut
- scene: le plateau fini une seconde, puis les couches s'envolent dans l'ordre inverse, « On le démonte »
- voiceover: Un échiquier qui reconnaît ses pièces.

## Frame 2 : Titre

- status: animated
- src: compositions/titre.html
- duration: 2.5s
- transition_in: cut
- scene: carton bois, « Couche par couche », titre en trois lignes, l'onde s'aplatit en soulignement cuivre

## Frame 3 : La base

- status: animated
- src: index.html (5,5 à 9 s)
- duration: 3.5s
- transition_in: cut
- scene: la coque tombe et se pose, « coque imprimée · {base_height_mm} mm »
- voiceover: Tout part d'une coque imprimée.

## Frame 4 : L'énergie

- status: animated
- src: index.html (9 à 13 s)
- duration: 4s
- transition_in: cut
- scene: « {cells} cellules », trois poses, « {battery} · {energy_wh} Wh · cellules plates »
- voiceover: Des cellules plates, pour rester fin.

## Frame 5 : Le cerveau

- status: animated
- src: index.html (13 à 17 s)
- duration: 4s
- transition_in: cut
- scene: le cerveau et la carte puissance tombent ensemble, « {mcu} · charge USB-C »
- voiceover: Le cerveau et sa carte de puissance.

## Frame 6 : Les quadrants

- status: animated
- src: index.html (17 à 23 s)
- duration: 6s
- transition_in: cut
- scene: « {quadrants} quadrants », quatre poses régulières, le compteur de spirales monte d'un quadrant à chaque pose, puis « {leds} LED »
- voiceover: Un quadrant par quart du plateau, tous identiques.

## Frame 7 : Le bois

- status: animated
- src: index.html (23 à 27 s)
- duration: 4s
- transition_in: cut
- scene: le contreplaqué recouvre tout, puis une vague de lumière traverse ses trous en diagonale, « {plywood_mm} mm · {leds} points lumineux »
- voiceover: Du bois par-dessus, la lumière passe au travers.

## Frame 8 : Une pièce

- status: animated
- src: index.html (27 à 32 s)
- duration: 5s
- transition_in: cut
- scene: gros plan sur e4, plateau vide : feutre, bobine et condensateur, aimant, coque, écartés et légendés ({felt_mm}, {pawn_coil_mm}, {coil_uh}, {pawn_magnet_mm}) ; ils s'emboîtent, la case s'allume, la note sonne, « {line.pawn-white.name} · {line.pawn-white.label} »
- voiceover: Dans chaque pièce, une bobine et un condensateur.

## Frame 9 : Les pièces

- status: animated
- src: index.html (32 à 38 s)
- duration: 6s
- transition_in: cut
- scene: « {lines_count} notes », les douze familles tombent chacune sur sa note, du plus grave au plus aigu
- voiceover: Chaque famille de pièces tombe sur sa note.

## Frame 10 : Terminé

- status: animated
- src: index.html (38 à 41,5 s)
- duration: 3.5s
- transition_in: same camera
- scene: la caméra s'approche du plateau fini, « {module_cm} cm », « {thickness_mm} mm d'épaisseur · sur batterie »
- voiceover: Fini, et sur batterie.

## Frame 11 : Base chariot

- status: animated
- src: index.html (41,5 à 47,5 s)
- duration: 6s
- transition_in: cut
- scene: plan large ; le module plateau se soulève avec ses pièces, la base fine sort, la base chariot entre, le module s'y pose, « {gantry_thickness_mm} mm · CoreXY · phase 2 »
- voiceover: Le même plateau change de base : le chariot, en phase 2.

## Frame 12 : Fin

- status: animated
- src: compositions/fin.html
- duration: 7s
- transition_in: cut
- scene: carton bois, titre, la gamme des douze notes et l'onde qui s'amortit, état du projet, adresse du dépôt, signature « Échec et Watt »

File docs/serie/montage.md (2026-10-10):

# Montage : gabarit, son, sous-titres, export, publication

Un épisode se monte en deux heures quand les rushes sont nommés et la
fiche écrite. Ce document fixe le gabarit pour que tous les épisodes
se ressemblent, quel que soit celui qui monte.

## Outils

| Besoin | Choix recommandé | Alternative |
|---|---|---|
| Montage | DaVinci Resolve (gratuit, timeline verticale, sous-titres automatiques, gestion couleur) | CapCut sur téléphone pour les épisodes simples |
| Enregistrement d'écran | OBS (Linux, macOS, Windows), ou l'outil natif | |
| Voix off | le téléphone en mode dictaphone dans un placard, ou Audacity | |
| Cartons et plateau de progression | Inkscape ou Figma, exportés en PNG 1080 x 1920 avec fond transparent | |
| Musique et sons | bibliothèques libres : Pixabay Music, YouTube Audio Library (usage hors YouTube autorisé pour la plupart des titres, vérifier), Freesound (CC0) | les sons intégrés de l'application, uniquement si on ne cross-poste pas |

## Gabarit de timeline

Un projet type à dupliquer, avec les pistes suivantes, de haut en
bas :

1. **Cartons** : titre d'ouverture (0,5 s), le chiffre, la décision,
   le plateau de progression final.
2. **Texte à l'écran** : les mots clés, un par plan maximum.
3. **Sous-titres** : générés puis relus, style unique (voir plus bas).
4. **Écrans** : enregistrements d'écran recadrés et zoomés.
5. **Vidéo B** : plans de coupe, ralentis.
6. **Vidéo A** : plans principaux.
7. **Voix off**.
8. **Sons** : clics, ringdown, signature sonore.
9. **Musique** : à -18 dB sous la voix, coupée net sur le verdict.

Ordre de montage : voix off d'abord (enregistrée à partir du script,
raccourcie au besoin), image ensuite calée sur la voix, texte, sons,
musique, sous-titres en dernier.

## Structure temporelle d'un épisode de 60 s

| Temps | Contenu | Règle |
|---|---|---|
| 0 à 2 s | accroche : le plan le plus fort, le texte le plus court | pas de titre, pas de logo, pas de bonjour |
| 2 à 3 s | carton titre 0,5 s | grotesque grasse, fond bois ou cuivre |
| 3 à 10 s | contexte en une phrase de voix off | un plan large ou un dessin sur la planche |
| 10 à 40 s | le geste : ce qu'on fait, plans de 2 à 4 s | une seule idée, alterner dessus, macro, épaule |
| 40 à 50 s | le résultat ou le raté, le chiffre | mono plein écran pour le chiffre |
| 50 à 57 s | la relance, face caméra ou voix off | la question de l'épisode suivant |
| 57 à 60 s | plateau de progression, une case s'allume, signature sonore | toujours identique |

Le compte à rebours reste affiché en permanence en bas à droite, hors
de la zone d'interface (au-dessus des 250 px du bas).

## Sous-titres

- Générés automatiquement (Resolve, CapCut) puis **relus mot à mot** :
  les termes techniques sont systématiquement massacrés (microhenry,
  ringdown, ferrite).
- Style : grotesque Bold 64 px, blanc, contour noir 4 px, pas de fond,
  centrés, tiers inférieur (entre 1 300 et 1 550 px de hauteur).
- Deux lignes maximum, 6 mots par ligne au plus, coupure aux
  respirations de la voix.
- Un mot clé par sous-titre peut passer en cuivre (#B87333) ou en
  cyan (#2EC4B6) pour la mesure ; jamais plus d'un.
- Pas de majuscules criées dans les sous-titres ; les majuscules sont
  réservées au texte à l'écran.

## Zones sûres (1080 x 1920)

| Zone | Réservée à | Ne rien y mettre d'important |
|---|---|---|
| 0 à 100 px (haut) | barre de statut, titre de la série en petit | |
| 100 à 250 px | nom de compte et boutons selon l'application | |
| 250 à 1 550 px | contenu | zone utile |
| 1 550 à 1 920 px | légende, boutons, barre de progression | sous-titres jamais ici |
| 0 à 120 px (bord droit), sur toute la hauteur | boutons like, commentaire, partage | |

## Son

- **Voix off** : niveau cible -16 LUFS intégré, crête -1 dB. Couper
  les silences de plus de 0,4 s. Pas de réverbération.
- **Musique** : un seul morceau par saison pour créer l'habitude, à
  -18 dB sous la voix, coupé net sur les verdicts et les ratés, puis
  reprise.
- **Signature sonore** : les douze notes du plan de fréquences
  ramenées mille fois plus bas (217 à 613 Hz), jouées en ringdown
  (attaque instantanée, décroissance exponentielle de 0,4 s), montante
  à l'ouverture, une seule note à chaque identification de pièce.
  L'outil existe : `python -m serie signature DOSSIER` lit les
  fréquences par `chessboard_calc` et écrit un `.wav` par note
  (`pawn-black.wav`...) plus la gamme montante (`gamme.wav`). Ses
  réglages (rapport de transposition, décroissance, harmoniques qui
  font passer les notes graves sur un haut-parleur de téléphone,
  pas de la gamme) sont dans la section `serie` de
  `config/board.yaml`. Les films de `media/pitch/` l'utilisent.
- **Sons de geste** : clic de relais, bip de terminal, cutter,
  perceuse : garder les sons réels des rushes plutôt que des banques.
  Ils sont plus crédibles.

## Cartons et éléments graphiques

Fabriquer une fois, réutiliser partout, dans `serie/cartons/` :

- `titre.png` : « Échec et Watt », fond bois, texte noir, souligné
  cuivre.
- `chiffre.png` : cadre pour « le chiffre », mono, fond noir, chiffre
  en cuivre, phrase en blanc.
- `decision.png` : cadre pour « la décision », numéro d'ADR en mono,
  titre en grotesque.
- `rate.png` : cadre pour « le raté », fond ambre, texte noir.
- `plateau_Exx.png` : le plateau de progression, une version par
  épisode (a1 allumé, puis a1 et b1, etc.), cases allumées en cuivre,
  case du jour en cyan.
- `jmoins.png` : gabarit du compte à rebours, mono, bas droit.
- Les images du dépôt (`docs/images/`) recadrées en vertical :
  architecture, empilement, plan de fréquences, rendus des cartes,
  puck éclaté.

## Étalonnage

- Un seul réglage par séance, copié sur tous les plans de la séance.
- Balance des blancs neutre sur le bois (le bois ne doit pas virer
  au jaune ni au rose), contraste modéré, saturation naturelle.
- Les plans d'écran ne s'étalonnent pas.
- Les ralentis à 60 i/s se ralentissent à 50 %, jamais moins (sinon
  saccades).

## Export

| Paramètre | Valeur |
|---|---|
| Résolution | 1080 x 1920 |
| Cadence | 30 i/s |
| Codec | H.264, profil High, 20 à 25 Mbit/s |
| Son | AAC 48 kHz, 256 kbit/s, stéréo |
| Fichier | `exports/Exx_final.mp4`, versions intermédiaires `Exx_v1.mp4` |
| Durée | vérifier 45 à 75 s (90 s maximum pour E00, E10, E29) |

Exporter une fois, publier le même fichier sur toutes les
plateformes. Ne pas laisser une application recompresser un export
déjà passé par une autre.

## Fiche de publication

Par épisode, dans le journal de [tournage.md](tournage.md) ou une
note à part :

- **Titre** : le titre de la fiche, sans numéro à l'écran mais avec le
  numéro en légende (« E06 »).
- **Légende** : deux lignes : l'idée de l'épisode, puis la question de
  la relance. Trois à cinq mots-clés en fin de légende (échecs, DIY,
  électronique, impression 3D, bois), pas plus.
- **Vignette** : le plan d'accroche avec le texte d'accroche.
- **Heure** : publication en différé après Noël, un épisode par jour
  à la même heure, dans l'ordre ; programmer la file entière d'un
  coup avec l'outil de planification de l'application.
- **Secret** : relire la légende et la vignette pour vérifier
  qu'aucun prénom ne désigne le destinataire (jusqu'à E29), même si
  la série sort après la remise : c'est la révélation qui fait la
  chute.
- **Relecture d'ensemble** : avant de programmer la file, regarder
  tous les épisodes d'une traite pour vérifier le compte à rebours,
  le plateau de progression et les raccords entre épisodes montés à
  des mois d'écart.

## Checklist de sortie

- [ ] L'accroche tient en 2 s et sans le son.
- [ ] Une seule idée.
- [ ] Le chiffre vérifié contre `board.yaml` ou le rapport.
- [ ] Sous-titres relus, termes techniques corrects.
- [ ] Rien d'important dans les zones d'interface.
- [ ] Compte à rebours à jour.
- [ ] Plateau de progression : la bonne case allumée.
- [ ] Signature sonore à la fin.
- [ ] Aucun prénom ni indice sur le destinataire.
- [ ] Niveau sonore -16 LUFS, musique sous la voix.
- [ ] Durée entre 45 et 75 s.
- [ ] Fichier nommé `Exx_final.mp4`, publié depuis le même fichier
      partout.

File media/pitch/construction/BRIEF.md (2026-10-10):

---
workflow: general-video
flow: automation
storyboard: yes
message: "Couche par couche, ce qu'il y a sous le bois"
destination: tiktok
aspect: 1080x1920
language: fr
audience: "financement participatif, promo et vlog Instagram et TikTok"
length: 54.5s
angle: "le plateau se construit"
---

## Intent

Film de présentation de l'échiquier à détection LC, version « Le plateau
se construit » : le plateau fini, démonté en accéléré, puis remonté du
fond de la base jusqu'aux pièces, une pièce ouverte au passage, et pour
finir le même module plateau posé sur la base chariot de la phase 2.
Ton documentaire, très calme. Public : financement participatif, et
surtout promo et vlog sur Instagram et TikTok, donc vertical d'abord.
Le titre affiché suit la version.

## Customizations

- Une seule scène Three.js à la racine, sur le temps global du film.
  Chaque couche est le vrai solide CadQuery (`mechanical/scenes.py
  --film-meshes`) : base fine, trois cellules, cerveau et carte
  puissance, quatre quadrants, contreplaqué, puis la base chariot. Les
  pièces Staunton et la pièce ouverte (feutre, bobine et condensateur,
  aimant, coque) sont dessinées sur les cotes de `chessboard_calc`, dans
  [`../commun/scene3d.js`](../commun/scene3d.js).
- Une seule caméra documentaire qui tourne lentement autour du plateau ;
  deux exceptions coupées franc : le gros plan sur la pièce ouverte, le
  plan large du changement de base.
- Son de synthèse seul : un bruit sourd à chaque couche posée
  (`pose.wav`), la note du pion quand la pièce se referme, puis les douze
  familles de pièces qui tombent sur les douze notes de la gamme, un pas
  de gamme (`serie.scale_step_s`) entre deux familles.
- Direction artistique, zones sûres, sous-titres et grammaire de
  montage de la bible de la série ([docs/serie](../../../docs/serie/README.md)),
  signature « Échec et Watt » sur le carton de fin.
- Tous les chiffres passent par `data-fact` et `assets/facts.js`,
  jamais tapés dans une composition (`tests/test_serie.py`) ; le
  compteur de spirales est calculé depuis `spirals_per_quadrant`.

## Notes

- Voix off plus tard : doublage par Étienne ou voix de synthèse
  (ElevenLabs), à décider. Les sous-titres de `compositions/captions.html`
  sont écrits pour servir de script.
- La base chariot est la phase 2 du projet : le film le dit à l'écran.
- Le rendu 3D passe par le navigateur sans interface et le moteur
  logiciel (SwiftShader) : compter une vingtaine de minutes à 30 i/s.

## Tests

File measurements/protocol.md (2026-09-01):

# Protocole de mesure de la maquette 2 x 2

Objectif : trancher les incertitudes du brief (section 6, mesures 1 à
8) plus les extensions issues de la lecture critique. La mesure 2
valide ou invalide le pivot de l'architecture (aimant ferrite), la 4
oriente le choix du MCU, la 7 dimensionne l'interlock, la 8 arbitre
l'alimentation.

## Matériel

- Carte bobines + carte analogique assemblées, Nucleo-G474RE flashée
  (`firmware/mockup`), console série 921600 bauds.
- 4 pucks de test imprimés avec résonateurs bobinés : 12 nF (pion
  noir, 217 kHz), 10 nF (cavalier, 237), 8,2 nF (fou, 262), 6,8 nF
  (tour, 288). Bas de bande volontairement : si ces quatre-là se
  discriminent, le reste de la table est acquis.
- Aimants : ferrite SrFe ø12,5 x 4 (pucks) et N42 ø15 x 5 (support
  réglable), un aimant néodyme supplémentaire pour la mesure 3.
- Oscilloscope conseillé sur TP1 (INA) et TP2 (AMP_OUT) mais le
  firmware suffit pour tous les critères chiffrés.
- Optionnel : LCR-mètre pour L et Q de référence des bobines nues.

Relevés : un fichier CSV par mesure dans `measurements/data/`, gabarits
dans `measurements/data/templates/`, analyse par
`measurements/analysis.ipynb` (fonctions dans `analysis.py`).

## Séquence recommandée

Chaque mesure indique : préparation, acquisition, critère.

### M1. Q du résonateur seul (critère : >= 40 par classe de diamètre)

Par puck, SANS aimant : poser le puck sur sa case, `r` (dump brut),
sauver en `m1_q_<classe>.csv`. L'analyse extrait Q par décrément
logarithmique de l'enveloppe (référence, vérifiée à 2 % sur signaux
synthétiques) ; la largeur spectrale ne fournit qu'une borne
inférieure avec 512 points. La modélisation prévoit le pion
comme cas limite : si Q < 40, essayer le fil de Litz avant de
conclure.

### M2. Q avec aimant ferrite (critère : >= 30 et chute <= 20 %)

Insérer les aimants ferrite dans les pucks, refaire M1 en
`m2_q_ferrite_<classe>.csv`. C'est la mesure pivot : un échec ici
remet l'architecture en cause (repli : reed switches).

### M3. Q avec aimant néodyme, comparaison (chute attendue 40 à 70 %)

Remplacer le ferrite par un N42 équivalent dans un puck,
`m3_q_neodyme.csv`. Quantifie ce que la décision ferrite évite.

### M4. Amplitude et SNR à l'entrefer nominal (critère : SNR >= 20 dB)

Pucks complets, entrefer nominal (PCB + surface 3 mm, bois ou
acrylique selon M10, + feutre).
`s` puis `m` pendant 60 s, `m4_snr.csv`. Critère sur la colonne
snr_db10 (>= 200). Extension M4bis : répéter avec cales à l'entrefer
max 8 mm, critère SNR >= 10 dB.

### M5. Diaphonie case voisine (critère : <= -20 dB)

Un seul puck sur S1, scanner S1 à S4. Rapport d'amplitude
S2/S1 en dB, `m5_diaphonie.csv`.

### M5bis. Détuning mutuel entre résonateurs identiques (< 3 kHz)

Extension de la lecture critique (D) : la position initiale aligne
des pièces identiques. Mesurer f du 12 nF seul sur S1, puis avec un
second 12 nF sur S2 (et S3 si disponible), `m5bis_detuning.csv` :
décalage de fa < 3 kHz.

### M6. Dispersion de f sur 4 bobines main (critère : <= +-3 %)

Bobiner 4 bobines identiques (même gabarit), les mesurer tour à tour
dans le même puck avec le même condensateur, `m6_dispersion.csv`.
Valide l'hypothèse de calibration sans tri.

### M7. Approche du N42 par dessous (dimensionne le parking)

Support réglable sous S3, puck sur S3. Descendre l'aimant par pas de
1 mm (vis M3 : 0,5 mm par tour), relever fa et amp à chaque pas,
`m7_parking.csv`. Chercher la distance où le décalage dépasse 2 kHz :
c'est la distance de parking minimale. Extension M7bis : mesurer
aussi l'effort d'arrachement sur le puck (l'aimant rétracté passera
sous des pièces stockées en bande).

### M8. Plancher de bruit et architecture d'alimentation (<= 6 dB)

Sans puck, dump brut `r` répété dans chaque configuration,
`m8_bruit_<config>.csv` :

1. alimentation analogique par LDO (JP1 côté LDO), Pi absent ;
2. LDO, Pi alimenté sur J5 mais idle ;
3. LDO, Pi en émission WiFi (iperf) ;
4. buck filtré (JP1 côté buck), JP3 en forced PWM, mêmes trois cas ;
5. buck en PFM (JP3 côté PFM) : quantifie le piège des rafales.

Critère du brief : delta <= 6 dB entre Pi éteint et WiFi en émission
avec les mitigations en place. Comparer aussi buck FPWM contre LDO :
si l'écart est < 3 dB, le buck seul suffit au plateau final.

### M9. Comparaison des voies A et B (décision 5.2)

Transversale : chaque CSV contient fa et fb. L'analyse produit
biais, écart-type et taux de rejet de la voie B en fonction du SNR.
Décision : si fb est disponible et stable (écart-type < 200 Hz) sur
M4, la voie B gagne et le choix du MCU s'ouvre.

### M10. Surface bois contre acrylique (ADR 0009)

Poser successivement la plaque d'acrylique 3 mm puis la planche de
contreplaqué (même épaisseur si possible, sinon noter l'écart) entre
la carte bobines et la pièce de test, sans rien changer d'autre.
Relever pour la case 1 : fa, amplitude et SNR, 16 mesures par surface.
Refaire la série bois après 24 h dans une pièce humide (salle de
bain) pour borner l'effet de l'humidité.

Critère : décalage de fréquence < 500 Hz entre surfaces (attendu :
quelques Hz), chute d'amplitude cohérente avec l'écart d'épaisseur
seul, chute de Q < 10 % même bois humide.

### M11. Bruit des LED de camp (ADR 0009)

Sur la case 1 avec pièce posée : série de 16 mesures LED éteintes
(commande `o`), puis 16 avec les 8 LED au blanc plein (`l` après une
calibration factice, ou en forçant les couleurs), la trame étant par
construction envoyée hors mesure. Comparer plancher de bruit, sigma
de fa et amplitude.

Critère : aucun écart mesurable de sigma fa (< 100 Hz) ni du plancher
(< 1 dB) entre LED éteintes et allumées statiques.

## Tableau de synthèse à remplir

| Mesure | Critère | Résultat | Verdict |
|---|---|---|---|
| M1 | Q >= 40 | | |
| M2 | Q >= 30, chute <= 20 % | | |
| M3 | informatif | | |
| M4 | SNR >= 20 dB | | |
| M4bis | SNR >= 10 dB a 8 mm | | |
| M5 | <= -20 dB | | |
| M5bis | < 3 kHz | | |
| M6 | <= +-3 % | | |
| M7 | distance pour < 2 kHz | | |
| M8 | delta <= 6 dB | | |
| M9 | sigma fb < 200 Hz | | |
| M10 | df < 500 Hz, dQ < 10 % | | |
| M11 | dsigma < 100 Hz, < 1 dB | | |

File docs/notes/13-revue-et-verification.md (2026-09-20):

# Note 13 : ouvrir, vérifier et tester les cartes

Où regarder et quoi lancer pour passer des fichiers générés à des
cartes commandées puis mesurées. Tout part de `config/board.yaml` ;
un chiffre qui n'en découle pas est suspect.

## 1. Ouvrir un projet dans KiCad 9

Les cinq projets sont dans `hardware/<carte>/<carte>.kicad_pro`
(`quadrant`, `brain`, `power`, `motion`, `clock`) ; la maquette 2 x 2
de référence dans `hardware/mockup-2x2/`.

- Fichiers au format KiCad 7 : KiCad 7, 8 ou 9 les ouvrent, 8 et 9
  proposent la conversion au premier enregistrement. Symboles et empreintes sont
  embarqués, rien à installer. Le `.kicad_prl` créé à l'ouverture est
  ignoré par git ; une régénération remet le projet dans son état
  canonique (voir la [note 08](08-regenerer.md)), donc modifier le
  générateur plutôt que le fichier quand la modification doit durer.
- Modèles 3D : pointer `KICAD6_3DMODEL_DIR` (ou la variable de votre
  version) vers les modèles de la distribution si la vue 3D reste vide.
- Le schéma est généré en feuille unique, groupé par bloc fonctionnel
  (cellules, mux, chaîne, alimentation...). Il porte les mêmes nets
  que le PCB : `tests/test_quadgen.py::test_schematic_exports_a_netlist`
  et `tests/test_boardgen.py::test_schematic_netlists` exportent la
  netlist avec `kicad-cli` et la comparent au circuit Python.

## 2. Vérifier que tout correspond

| Question | Où c'est garanti | Ce qu'il reste à faire à la main |
|---|---|---|
| Le PCB suit le schéma | même objet `Circuit` pour les deux, netlist exportée et comparée par les tests | rien, sauf après une retouche manuelle dans pcbnew : relancer « Mettre à jour le PCB depuis le schéma » ne s'applique pas (schéma généré), comparer plutôt avec `Outils > Comparer les netlists` |
| Les broches des circuits intégrés | symboles des bibliothèques officielles KiCad, câblage par nom de broche (`pins_by_name`), refus de toute broche inconnue ou oubliée, netlist exportée par `kicad-cli` égale au circuit (`tests/test_schematics.py`) | relus dans la [note 14](14-revue-des-cartes.md) : STM32G474 conforme, BQ24610 et BQ76920 corrigés (FET d'entrée, FET de protection, réseau TS, consignes), UART de l'ESP32 corrigée ; restent à confirmer sur les fiches les formules ISET du BQ24610 et l'ADG1607 en 5 V simple, et à trancher le type des câbles FPC |
| Les valeurs des composants | dérivées du yaml par `chessboard_calc` et épinglées par `pytest` ; `python -m chessboard_calc.report` imprime tout (fréquences des 12 classes, Q, séparation, bobines, entrefer, budget de puissance, autonomie) | les consignes de charge (ISET, ACSET, diviseur VFB, CTN) suivent l'application type de TI : revue en lisant la fiche BQ24610 ; les diviseurs de mesure et les RC de sortie se relisent sur le schéma |
| Les pistes | contrôle d'isolement exact (shapely) à chaque build et sur chaque route candidate, largeur et isolement dans le `.kicad_pro`, règles du projet égales à ce que le build a dessiné | lancer le DRC : `tools/drc.py` avec le Python de KiCad (`/usr/bin/python3 tools/drc.py hardware/brain/brain.kicad_pcb`), ou `Inspection > Contrôle des règles` dans KiCad 9 ; fermer les nets ouverts listés dans le README de chaque carte ; confirmer les vias 0,45 mm chez le fabricant. Bilan de la revue du 03/09/2026 dans la [note 14](14-revue-des-cartes.md) |
| L'intégrité de signal | plan de masse continu, RC devant chaque ADC, buck 2,5 MHz en PWM forcé loin de l'analogique, lignes de mesure sur B.Cu et grille sur In2 du quadrant ([note 11](11-cartes-du-plateau.md)) | revue visuelle des retours de masse sous les lignes de mesure après fermeture manuelle des nets |
| La mécanique | `tests/test_plateau.py` (empilement, empreintes des cartes dans la base, LED dans leur case), vues éclatées | rien avant impression |

## 3. Simuler

- Chaîne d'amplification du quadrant : `hardware/quadrant/chain-spice.cir`
  (AD8421 en gain 20 puis Sallen-Key passe-haut et passe-bas), à
  lancer avec `ngspice -b hardware/quadrant/chain-spice.cir`. Le
  critère : gain plat de 200 à 650 kHz, coupures à leur place.
- Cellule d'excitation et amortissement : pas encore de banc SPICE ;
  à écrire sur le modèle du `chain-spice.cir` avant la commande
  (bobine 16 µH, écrêteurs, AO3400A, roue libre).
- Sous-circuits détectés (filtres, diviseurs, gains) : le skill `spice`
  génère et lance les bancs ngspice tout seul ([note 15](15-skills-embarques.md)).
- Résonateurs et couplage : ce sont des calculs fermés
  (`chessboard_calc`), pas des simulations ; le rapport donne les
  largeurs de raie et la marge de séparation.

## 4. Commander

Le runbook de commande, carte par carte, avec les options écran par
écran, la fabricabilité mesurée et ce qui manque pour un ordre
d'assemblage, est la [note 23](23-commande-jlcpcb.md). L'audit se
rejoue en une commande, `python3 tools/fabcheck.py`. Ce qui suit reste
vrai et le complète.

- Quadrant : 4 couches, 1,6 mm, 1 oz, assemblage face top ; commander
  quatre exemplaires du même fichier. `jlc-bom.csv` et `jlc-cpl.csv`
  sont dans `hardware/quadrant/`, gerbers par `tools/gerbers.py`
  ([note 08](08-regenerer.md)) une fois les nets fermés : l'outil les
  refuse tant qu'il reste une pastille non connectée, et il y en a 347.
- Les cartes à routage fermé sont les seules dont les gerbers soient
  produits par `tools/gerbers.py` : les deux cartes du banc,
  `hardware/bench/bench-gerbers.zip` et
  `hardware/quadrant-2x2/quadrant-2x2-gerbers.zip`, et la carte
  analogique de maquette,
  `hardware/mockup-2x2/analog-board/analog-board-gerbers.zip`. Chacune
  porte son empreinte `*-gerbers.sha256`, à vérifier par
  `sha256sum -c` avant de téléverser. La carte bobines de la maquette
  n'en a plus : son archive ne correspondait plus à sa carte
  ([note 22](22-erreurs-de-conception.md), point 10).
- Cerveau : 4 couches. Puissance, moteurs, horloge : 2 couches.
- Les codes LCSC du BOM sont des candidats saisis hors ligne : vérifier
  chaque ligne dans la prévisualisation JLCPCB (mêmes réserves que pour
  la [maquette](../../hardware/mockup-2x2/README.md)). Les skills
  `release-pcba-fabrication` (version figée avec empreintes de hachage
  et manifeste) et `operate-jlcpcb-order` (parcours de commande avec
  contrôle de l'aperçu de placement) encadrent cette étape,
  [note 15](15-skills-embarques.md).
- La carte moteurs n'est utile qu'avec la base chariot : commander plus
  tard.

## 5. Tester

Dans l'ordre, un quadrant seul puis le cerveau :

1. **Quadrant hors tension** : continuité des bus (5VA, VREF,
   DRIVE_BUS, VIN, GND sur les points de test TP1 à TP4), absence de
   court entre rails, chaque bobine mesurée entre ses deux bornes
   (environ 16 µH, quelques ohms).
2. **Cerveau seul** : alimenter par une alimentation de laboratoire
   limitée en courant sur VBAT_IN (embase J10, 9 à 12,6 V ; le USB-C ne
   porte que les données), vérifier 5 V, 3,3 V, 5VA dans l'ordre,
   courant au repos, console série (`firmware/board`, 115200 bauds,
   commande `h`).
3. **Quadrant sur le cerveau** : nappe FPC, `1` scanne les 16 bobines,
   CSV `q,coil,sq,fa_hz,fb_hz,amp_mv,snr_db10`. Un puck de test posé
   sur une case doit donner sa fréquence de classe et un SNR positif.
4. **Mesures M1 à M11** du [protocole](../../measurements/protocol.md) :
   écrit pour la maquette, il s'applique tel quel avec le quadrant à
   la place de la carte bobines et le cerveau à la place de la Nucleo ;
   les CSV vont dans `measurements/data/`, l'analyse dans le notebook.
5. **LED** : `l` allume les camps, `o` éteint ; vérifier la chaîne des
   quatre quadrants par la sortie DOUT.
6. **Puissance** : d'abord sans cellules avec une alimentation de
   laboratoire limitée en courant sur PACK+, puis avec les cellules et
   la charge par USB-C PD, en surveillant les tensions de cellule par
   l'INA219 et le BQ76920 sur I2C.
7. **Horloge** : compilation ESP-IDF sur poste (`firmware/esp32`),
   barre, encodeur, buzzer, écran, puis appairage BLE avec le pont du
   cerveau et échange des lignes `C`, `T`, `N` de la [note 12](12-protocole.md).

## 6. Fichiers d'impression

`python mechanical/build_all.py` écrit les STL et STEP dans
`mechanical/exports/` (ignoré par git, une minute de calcul) : socle
fin, socle chariot, module plateau, boîtier, fond et barre de
l'horloge, pucks de test, gabarits de bobinage, support d'aimant.
Les STEP s'importent dans KiCad 9 pour vérifier les cartes dans leur
base.

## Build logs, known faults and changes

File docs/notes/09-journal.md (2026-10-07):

# 09. Journal des décisions et pivots

Chronologie condensée, source : l'historique git (`git log --reverse`)
et les ADR. Les entrées gardent le pourquoi, pas le détail (le détail
est dans les notes 03 à 06).

## 29/08/2026, fondations (phase 0)

- Socle : `board.yaml` unique source, `chessboard_calc`, garde-fou
  couloir bloquant en CI, conventions du dépôt (français, pas de
  tirets longs, travail sur `main`).
- Décisions structurantes posées en ADR : résonateurs LC passifs
  (0001), **aimants pièces en ferrite et jamais néodyme** (0002, la
  décision pivot du projet), STM32 maître et Pi optionnel (0003),
  détection PCB quatre quadrants (0004), architecture d'alimentation
  et de bruit (0005), pas p ouvert 40/50 paramétrique (0006), double
  voie d'extraction FFT plus période (0007).

## 29/08/2026, la maquette prend forme

- ADR 0008 : maquette en deux cartes ; le mux pressenti ADG709 est
  écarté au profit du **74HCT4052** (seuils TTL pilotables par un MCU
  3,3 V sur un rail 5 V), excitation hors mux par FET dédié.
- `coilgen` : spirales 4 couches en série ; leçon : les jonctions
  inter-couches alignées sur le rayon du terminal superposaient les
  vias, d'où les arcs de liaison à 90 degrés. Les trous du support
  d'aimant passent de 30 à 34 mm pour ne pas percer la spire externe.
- Firmware compilable (CMSIS nu), mécanique CadQuery, protocole M1 à
  M9, visuels, tests analoggen : la phase 1 est presque complète en
  une journée, sauf le routage.

## 29 au 30/08/2026, la bataille du routage

Progression des liaisons ouvertes de la carte analogique : 57, 51,
46, 40, 21, 16, 12, 9. Les jalons :

- Rasterisation conservative et marquage du cuivre à l'étendue vraie ;
  marge de routage relevée contre l'arrondi de grille.
- Méthode des **seeds répétés hors build** contre la géométrie réelle
  des pads, avec gardes au build (note 05) ; leçons payées : rayon des
  vias contre les rails, moignons de sortie, croisements seed contre
  seed.
- **Passe de garantie** : tout cuivre sous la garde de fabrication est
  retiré et réouvert en chevelu ; la carte part toujours DRC zéro.
- **Autopsies géométriques exactes** du cuivre pré-retrait : trois
  trous de légalité réels identifiés et corrigés à la racine (frange
  de raster des cellules de départ, couloir own par les marques de
  pistes, moignons de masse trop larges) ; deux impasses essayées puis
  annulées (entrée cible libre, puis bornée).
- Constat de **saturation** : chaque seed supplémentaire dans la bande
  des cellules déplaçait plus de nets qu'il n'en fermait ; gel à 18
  restes, puis la **passe de finition à géométrie exacte** (note 04)
  les ramène à 9. L'histoire du canal de 0,52 mm : la garde passe de
  0,137 à 0,132 parce que 0,524 exigés dépassaient de quatre microns.

## 30/08/2026, approvisionnement

Fiche comparée Europe contre Asie, prix relevés et datés.
Enseignements chiffrés : AD8421 à moitié prix chez LCSC (3,69 contre
8,91 USD), ADuM1201 en rupture DigiKey mais plus de 11 000 en stock
LCSC, et le contre-exemple : la Nucleo est moins chère et plus sûre en
Europe (eStore ST) qu'en revendeur asiatique. Panaché conseillé en
quatre commandes.

## 01/09/2026, LED de camp et surface bois (ADR 0009)

- Demande produit : deux points lumineux par case indiquant le camp
  occupant, sur une surface en bois (référence visuelle : plateaux du
  commerce à points aux coins).
- Choix : 2 WS2812B par case aux coins opposés (un coin partagé entre
  deux cases de camps opposés serait ambigu), chaîne unique extensible
  au 8 x 8 ; analyse bois : effet nul sur la fréquence, seuls comptent
  l'épaisseur et l'humidité (mesure M10 ajoutée).
- Intégration : couloirs In1/In2/B de la carte bobines (note 05),
  joint porté à 12 broches, tampon 74AHCT1G125 côté analogique
  (déplacé près du connecteur MCU après un premier placement qui
  faisait échouer LED_DIN), pilote bit-bang DWT (TIM2 occupé par la
  capture), fenêtrage structurel (M11), gabarit de perçage
  `surface-template`.
- Leçon de re-routage : le déplacement du joint et les deux nets
  nouveaux ont d'abord déplacé cinq signaux ; le repositionnement du
  tampon a tout refermé côté LED. Référence : 499 pistes, DRC zéro,
  sept couloirs saturés restants.

## 02/09/2026, plateau 8 x 8 direct, base interchangeable, horloge (ADR 0010)

- Point de départ : ouverture des cartes de la maquette dans KiCad 9
  sous Debian, question « peut-on imprimer huit fois la carte bobines
  pour faire l'échiquier ». Réponse : non (64 cases, carte analogique
  à quatre voies, connecteurs de bord), et le porteur ne veut pas
  traîner plusieurs versions : on conçoit directement le 8 x 8.
- Choix successifs, avec leurs raisons dans la
  [note 10](10-plateau-8x8-et-horloge.md) : p = 50 (signal et Q du
  pion noir), quatre quadrants 4 x 4 intelligents, LED identiques sur
  toutes les cases, chariot optionnel dans une base clipsable avec les
  ailes de capture (inspiration Chessnut Air : plateau fin d'abord),
  électronique et cellules plates au fond de la base sur une empreinte
  commune (le bandeau arrière à 18650 a été refusé), MCU soudé,
  emplacement ESP32-S3 plus Pi, horloge séparée à bascule en BLE
  avec sa propre 18650.
- Outillage : rendu matplotlib jugé illisible, remplacé par un
  rasteriseur à tampon de profondeur et par une vue interactive
  three.js générée depuis les modèles CadQuery.
- Leçon : l'entrefer d'air sous le bois (LED de 1,6 mm) était
  implicite dans la maquette ; il est maintenant un paramètre
  (`gap.air_mm`) compté dans le signal.

## 03/09/2026, générateurs de cartes

- Quadrant : frontal complet (cellules, deux ADG1607, décodeurs,
  chaîne) placé et routé par un routeur A* multicouche écrit pour
  l'occasion ; cellules disposées autour des bandes d'échappée après
  qu'une garde trop laxiste (centre au lieu d'emprise) avait posé des
  composants sur les voies. Bande élargie à 20 mm et bordure bois à
  20 mm pour laisser de la place.
- Cerveau, puissance, moteurs, horloge : générateur générique
  `boardgen` (placement par blocs et étagères depuis les cours réels,
  routage en deux grilles, plan de masse), [note 11](11-cartes-du-plateau.md).
- Leçons : les fiches techniques externes ne sont pas accessibles
  depuis l'environnement de génération, donc chaque composant vient
  des bibliothèques KiCad (brochage vérifié) ou est marqué à vérifier ;
  un routeur qui gonfle les obstacles pour la piste large bloque les
  passages entre broches traversantes, d'où la grille séparée pour les
  signaux.
- Sorties des boîtiers fins : les nets des QFN, LQFP, TSSOP et
  connecteurs FPC restaient tous ouverts, le routeur ne pouvant pas
  quitter une broche au pas de 0,5 mm ; chaque broche reçoit un tronçon
  de sortie avant routage (`quadgen.escape`) et les passifs sont
  espacés de 1,2 mm pour laisser passer un via. Le premier essai
  traçait les tronçons dans la direction radiale, ce qui envoyait ceux
  des connecteurs en rangée sur la broche voisine : ils suivent
  désormais l'axe long de la broche. Les tronçons seuls ne suffisaient
  pas : tout bus routé devant une rangée la murait sur la couche
  supérieure, et un tronçon voisin routé rendait la grille aveugle au
  pas de 0,5 mm. D'où l'éventail complet (tronçon, petit via sur deux
  rangées alternées, couloir de sortie sur la couche interne, cellules
  rendues au net après chaque routage) et l'ordre de routage qui sort
  les boîtiers fins en premier, [note 11](11-cartes-du-plateau.md).
- Horloge sur le même module ESP32-S3-WROOM-1 que le cerveau (une
  référence, une chaîne d'outils) ; protocole texte commun
  ([note 12](12-protocole.md)), firmware du pont et de l'horloge
  écrits (`firmware/esp32`), logique de pendule testée sur PC.

## 03/09/2026, phasage et livrables

- Décision : phase 1 sans chariot jusqu'à une partie jouable de bout en
  bout, chariot en phase 2 ; la carte moteurs et la base chariot
  restent conçues mais ne sont ni commandées ni testées avant.
- STL et STEP de `mechanical/exports/` désormais versionnés, la vue 3D
  interactive reste régénérée à la demande ; schémas d'architecture et
  d'empilement refaits pour le plateau 8 x 8 ; note 13 (ouvrir,
  vérifier, tester) et note 07 réécrite en feuille de route.

## 03/09/2026, revue des cartes (lot 1)

- Le schéma généré du quadrant reliait GND à 5VA (groupes qui se
  chevauchaient) ; l'émetteur espace désormais les groupes d'après leur
  hauteur réelle et un test compare la netlist KiCad de chaque carte au
  circuit. Le DRC de KiCad, lancé par `pcbnew` (`tools/drc.py`), a montré
  que le lecteur de cours d'empreinte ne comprenait pas les bibliothèques
  KiCad 7 : cellule du quadrant recomposée sur les cours réelles, module
  ESP32 au bord du cerveau avec son antenne hors carte, cour réduite et
  assumée sur l'horloge ; règles du projet alignées sur les vias
  d'éventail, vias hors des trous de connecteurs, net tie des bobines
  déplacé hors du trou de via. Plus grave : les vias d'empilement des
  bobines, posées sur le rayon intérieur ou extérieur, recouvraient les
  spires des autres couches et court-circuitaient la bobine (le
  contrôle maison exemptait les paires A/B) ; elles sont désormais
  décalées radialement hors des bandes, la maquette reste à corriger.
- Erreurs de câblage corrigées : FET d'entrée du BQ24610 en canal P
  (ACDRV actif bas), sources des FET DSG et CHG du BQ76920, réseau de
  température et consignes de charge (50 mohms, 1 A), UART de l'ESP32
  croisée sur le cerveau, lecture de charge et rétroéclairage de
  l'horloge. Détail et points restants dans la
  [note 14](14-revue-des-cartes.md).

## 07/09/2026, skills embarqués

- kicad-happy passé en v2.2.1 (correctifs des analyseurs et de la
  simulation), et trois skills de pcba-design-skills embarqués pour le
  lot 3 (`release-pcba-fabrication`, `operate-jlcpcb-order`) et la
  relecture de routage (`pcb-layout-review`) ; les cinq autres écartés,
  raisons dans `VENDORED.md`. Usage par lot dans la
  [note 15](15-skills-embarques.md).

## 07/09/2026, doc alignée sur le yaml et coût des cartes

- La doc était en retard sur `config/board.yaml` : le README du
  quadrant annonçait 216 x 200 mm avec une bande de 16 mm, l'ADR 0010
  et la note 10 un module de 420 x 420 mm avec une bordure de 10 mm,
  l'ADG726 et une nappe IDC. Les valeurs vraies (bande et bordure de
  20 mm, quadrant 220 x 200, module 440 x 440, deux ADG1607, nappe FPC
  16 broches) sont maintenant dans ces trois documents et dans le
  README de la racine ; le yaml et `tests/test_plateau.py` n'ont pas
  bougé, la doc a rattrapé.
- Réflexion ouverte sur le coût des cartes, le quadrant en tête
  (220 x 200 mm, 4 couches, cinq pièces au minimum) : devis JLCPCB à
  demander avant toute décision, différentiel vrai contre
  single-ended à trancher avant de chiffrer, piste des tuiles
  100 x 100 examinée et non tranchée, quadrant intelligent à
  instruire en ADR. Le tout dans la [note 16](16-cout-des-cartes.md).

## 13/09/2026, le quadrant relu pour être redessiné

- Constat du porteur : ouvert dans KiCad, le schéma du quadrant (et du
  cerveau) ne montre aucune liaison entre composants. Cause : le schéma
  généré est « par étiquettes », une étiquette globale par broche et
  aucun fil ; la netlist est juste (note 14) mais rien n'est lisible.
- Note 17 : fonction du quadrant, cycle d'une mesure d'après le
  firmware, composants et rôle bloc par bloc, câblage broche à broche,
  variante 2 x 2 (4 cellules, un seul ADG1607, 120 x 100 mm) et deux
  points de conception relevés en relisant (retour de roue libre qui
  dépend de la lenteur de Q1, rappel du P-FET d'amortissement vers VIN
  sans effet derrière un 74HC154). Proposition : redessiner en feuilles
  hiérarchiques à fils depuis le même circuit Python, 2 x 2 d'abord.
- Le commit du 02/09 sur la série vidéo (calendrier, rôles, publication
  en différé), resté sur une branche de session, est repris sur `main`.

## 13/09/2026, schéma dessiné et quadrant 2 x 2

- Nouveau moteur de schéma (`analoggen/sheets.py`) : feuilles
  hiérarchiques, composants placés par gabarit et reliés par des fils,
  étiquettes globales pour les rails et le bus, locales pour les nets
  internes ; le dessin est vérifié contre le circuit avant écriture et
  la netlist relue par kicad-cli est comparée au circuit en test.
  Leçon : KiCad ne relie que des extrémités de segments, un point de
  jonction posé au milieu d'un fil ne connecte rien tant que le fil
  n'est pas coupé là ; et il repositionne les champs justifiés d'un
  symbole tourné, d'où des textes centrés à position calculée.
- Circuit du quadrant : diode de roue libre par cellule et R7 à
  470 ohms (le rail doit être coupé avant la fenêtre d'écoute, pas
  maintenu), rappel du P-FET d'amortissement supprimé, spirale dessinée
  en inductance, écrêteurs BAV99W en SOT-323 pour loger la diode de
  roue libre dans la cellule ; les résistances restent en 0603, un
  essai en 0402 laissait le routeur sans point de départ sur 44
  pastilles de VREF du 4 x 4.
- Quadrant réduit 2 x 2 (`--reduced`, `plateau.quadrant.reduced`) :
  quatre cellules, un mux, huit LED, bande de frontal qui dépasse de
  2 p vers le sud, même firmware.

## 17/09/2026, carte de banc fermée, cœur de boardgen corrigé

- Carte de banc (shield Nucleo du quadrant 2 x 2) fermée jusqu'au
  bout : 29 nets, zéro ouvert, DRC KiCad zéro défaut. Le DRC comptait
  31 connexions manquantes là où le build en annonçait six : couloirs
  de sortie des vias d'éventail sans cuivre, routes finissant sur le
  coin arrondi d'une pastille, pastille déclarée atteinte sans preuve,
  piste de puissance refusée le long d'une piste d'envol, seeds d'un
  net jamais rejoints. Tous corrigés dans le cœur, qui vérifie
  maintenant la connexité exacte de chaque net après routage
  ([note 04](04-routeur-et-garanties.md)).
- Les liaisons que le routeur ne trouve pas sont dessinées comme dans
  pcbnew mais dans le générateur : éventail du FH12 à seize broches sur
  les deux faces, sorties du buck, longues liaisons 3V3, 5V_LED et
  AMP_OUT1 en face avant ([note 05](05-seeds-et-couloirs.md), README
  de la carte). KiCad 7.0.11 installé dans l'environnement pour le
  DRC ; les empreintes posées reçoivent des `tstamp` uniques, sans
  quoi le rapport DRC nomme les mauvais éléments.

## 19/09/2026, la carte analogique de maquette fermée

- Point de départ : KiCad comptait vingt-huit éléments non connectés
  sur la carte commitée, le build en annonçait sept. L'écart venait du
  modèle : la masse n'était pas vérifiée, les couches étaient
  fusionnées sans exiger de via, et une pastille valait la boîte
  autour d'elle. Le modèle exact du quadrant a été branché sur la
  carte analogique (`tools/analoggen/connect.py`), avec la forme vraie
  des pastilles et le plan de masse calculé comme le calcule le
  remplisseur de KiCad, îlot par îlot.
- Résultat immédiat : dix-neuf des vingt-huit liaisons manquantes
  étaient des masses, des groupes de pastilles reliés entre eux en
  face avant mais jamais descendus vers un îlot que le plan gardait
  entier. Une passe de finition de la masse, jouée contre les îlots
  réels, les a fermées.
- Deux outils ajoutés : un **labyrinthe** à géométrie exacte
  (`tools/analoggen/maze.py`, trame 0,05 mm, deux couches, via et
  coude payants) pour les liaisons qu'aucun raccord simple ne ferme,
  et des **routes structurelles** tracées avant le routage dans des
  canaux mesurés libres de pastilles.
- Deux défauts que la fermeture a mis à nu, corrigés dans la foulée :
  la broche 2 du jack, 1 mm hors du contour depuis l'origine (le jack
  recule à x = 8, son corps dépasse à l'ouest comme il se doit), et le
  fichier de carte qui déclarait quatre couches cuivre pour une carte
  deux couches, ce qu'un fabricant aurait facturé et gravé tel quel.
  Les gerbers de la carte sont désormais produits par
  `tools/gerbers.py`, pours remplis, et commités.
- Puis les 49 chevauchements de courtyard, la dernière famille que le
  DRC signalait encore. Quarante-quatre venaient du motif de cellule,
  dont les rangées étaient espacées sur les pastilles et non sur les
  courtyards ; les cinq autres, de voisinages serrés autour du jack et
  du réservoir. Le placement est repris, et le build vérifie désormais
  cette famille lui même (`tools/analoggen/yards.py`).
- Le prix du déplacement : tout le routage se rejoue. Trois tours de
  build ont été nécessaires, et chacun rouvrait deux à cinq liaisons
  ailleurs. La réponse n'a pas été de les fermer une à une mais de
  poser ce qui manquait structurellement : une **épine de masse** par
  cellule sur la face arrière, avec la descente de ses deux pastilles
  les plus fragiles, et une nappe pour la ligne la plus longue de la
  carte, celle que le routeur essaie en dernier quand la bande sud est
  pleine.
- Le placement corrigé a rouvert le routage une dernière fois, et la
  réponse a de nouveau été structurelle plutôt que liaison par
  liaison : la traversée de sa rangée par la ligne B de chaque
  cellule, face avant, dans le canal de 0,86 mm entre les deux
  rangées ; le contournement du coin sud-est, qui ne porte aucune
  pastille, pour la ligne B de la cellule 4 ; la descente de sa rangée
  B par la face arrière de la bande, où l'écrêteur et le FET, tous
  deux en CMS, ne bloquent rien ; une épine de masse pour le tampon
  LED, coincé sous le connecteur Nucleo entre vingt échappées ; un
  tour de routage de plus, puisque chaque tour promeut ce que le
  précédent a manqué ; et un labyrinthe qui dégrossit sa trame (0,1
  puis 0,2 mm) quand la liaison traverse la carte, au lieu
  d'abandonner sur son plafond d'exploration. Résultat : **568 pistes,
  288 vias, zéro liaison ouverte, zéro DRC, zéro chevauchement**.
- Deux tentatives ont coûté un build chacune et valent d'être notées,
  parce qu'elles disent la même chose : une amorce posée dans un
  couloir occupe ce couloir. Une descente de masse tracée au milieu de
  la colonne d'échappée du connecteur a rouvert trois lignes
  d'excitation ; remise en épine, parallèle aux échappées au lieu de
  les croiser, elle ne gêne plus personne. Avant de poser une route
  structurelle, regarder par où passent celles qui existent déjà.
- Leçon retenue et écrite dans la [note 04](04-routeur-et-garanties.md) :
  la « saturation » qui justifiait d'arrêter à sept liaisons était un
  artefact du compte. Un mauvais arbitre fait prendre les mauvaises
  décisions pendant des jours ; le compte exact a renversé la
  conclusion en une journée.

## 20/09/2026, devis, passe de finition partagée, cerveau et 4 x 4

- Le devis JLCPCB de vingt cartes 2 x 2 (281 EUR) est démonté ligne par
  ligne ([note 23](23-commande-jlcpcb.md), le document « Cartes du
  damier ») : six codes LCSC sur douze étaient des candidats jamais
  vérifiés et JLCPCB les a pris au mot, dont un codec audio à 7,47 EUR
  pièce à la place de l'AD8421 (149 EUR sur 281). Le format au dessus
  de 100 x 100 ne coûte que le frais d'ingénierie, 21,73 EUR par
  commande ; un 2 x 2 en 100 x 100 serait un nouveau plan de frontal
  en croix entre les bobines, 3 à 5 jours, et l'offre spéciale impose
  0,5 oz interne. Décision en attente : tuile du plateau ou carte de
  mise au point.
- KiCad 7.0.11 et ses bibliothèques s'installent dans l'environnement
  distant depuis l'archive Ubuntu (les PPA sont bloqués) : DRC, gerbers
  et tests des générateurs y tournent.
- Le firmware du banc pilote un quadrant 4 x 4 complet sur le même
  shield : `make NUCLEO=1 NUCLEO_FULL=1`, seize bobines derrière
  MUX_EN_H, chaîne de 32 LED générée du yaml ; budget du banc et
  précaution sur le courant des LED dans la note 19.
- La passe de finition et le labyrinthe de la carte analogique sont
  portés sur le modèle de cuivre partagé (`tools/quadgen/finish.py`,
  [note 04](04-routeur-et-garanties.md)) et branchés sur les trois
  générateurs ; un instantané du routage (`QUADGEN_DUMP`,
  `BOARDGEN_DUMP`, `--resume`) permet de rejouer la passe et les
  contrôles en secondes. Leçons : borner la famille à deux vias (neuf
  minutes sur un cas de vingt millimètres avant), faire partir le
  labyrinthe de la plus petite pièce, essayer le via fin après le via
  standard, donner un budget de temps à chaque net.
- Cerveau, régénéré : 23 nets ouverts, presque tous aux quatre
  connecteurs FPC dont les broches sont murées par leurs propres
  éventails ; le bus routé en premier plus la passe de finition en
  laissent 18. Réponse structurelle, comme sur le banc : les éventails
  des quatre liens sont dessinés à la main sur la face avant (voies de
  0,3 mm en escalier, un petit via au bout de chacune, les masses
  descendues au plan à leur moignon), la bande médiane descend de
  2,2 mm sous eux.
- Quadrant 4 x 4, régénéré pour la première fois depuis la comptabilité
  exacte : 36 nets ouverts, les entrées des deux mux, les sorties des
  décodeurs, la colonne des amplificateurs, 5VA, VREF et sept îlots du
  plan de masse ; le routage seul prend 27 minutes.
- Estimation du prix du plateau, cartes nues et assemblées, poste par
  poste (note 23, section 8) : 300 à 350 EUR hors taxes en cartes nues,
  430 à 480 EUR assemblé, dont 120 à 140 EUR de silicium analogique
  pour les quatre frontaux.

- Cerveau fermé, le soir : VBAT posé à la main sur la face arrière
  (bord sud, puis une colonne à l'ouest du lien puissance, jusqu'au
  fusible), les LED d'état à côté de leurs résistances, le bus, les
  alimentations, les sorties analogiques et l'UART de l'isolateur
  routés en premier, et un rip-up et reroutage des nets murés dans
  `boardgen` (un net à la fois, ses voisins soulevés, la levée gardée
  si elle ferme quelque chose). Douze builds de vingt minutes dans la
  journée. Résultat : 0 net ouvert, 0 élément non connecté au DRC de
  KiCad, `brain-gerbers.zip` et son empreinte commités ; le cerveau
  rejoint le 2 x 2 et le banc parmi les cartes commandables nues.
- Quadrant 4 x 4 : deux variantes de plus (broches fines en premier,
  face arrière moins chère), 47 nets ouverts dans tous les cas. Le
  diagnostic est écrit (note 04) : trois champs d'échappées, les
  multiplexeurs LFCSP face à face, les décodeurs à une rangée de vias,
  la colonne d'amplification ; le remède est celui du cerveau, des
  éventails dessinés à la main, un à deux jours. Le build du 20/09 est
  commité, sans archive.

## 20/09/2026, la liste d'achat du plateau

- `tools/bomagg.py` agrège les BOM générés d'un jeu de cartes avec leur
  multiplicateur : le plateau fait **1 399 composants en 71 lignes
  d'achat**, 1 584 unités avec la règle de rechange. Les prix vivent
  dans `docs/prix-plateau.csv`, une ligne, un statut, une source ; la
  [fiche](../bom-plateau.md) explique, l'outil compte.
- Les trois paniers : 138 USD tout LCSC mais incomplet (l'OPA2810 n'y
  est pas), 379 USD tout Mouser mais incomplet aussi (la WS2812B n'y est
  pas), **180 USD en prenant le moins cher ligne à ligne**, soit 199 EUR
  TTC. Un quadrant coûte 32,44 USD de composants, le cerveau 18,63 USD :
  la note 23 les surestimait d'un tiers.
- Deux constats qui commandent la suite : **l'ADG1607, l'AD8421 et
  l'OPA2810 font 63,2 % du panier** (la mesure que la note 16 attendait
  pour rouvrir le single-ended), et **neuf codes LCSC sur les cartes du
  plateau sont faux, manquants ou pointent une autre variante**, dont le
  FH12-16S obsolète et en rupture. Même famille d'erreur qu'au point 11
  de la note 22, détectée cette fois par un test.

## 04/10/2026, les éventails du quadrant 4 x 4, et le palier

- Le lot décrit le 20/09 est fait (note 04, section « Ce que le routeur
  ne peut pas trouver (quadrant 4 x 4) ») : les deux multiplexeurs
  tournés sur une même colonne avec leurs seize entrées dessinées à la
  main (vias dans deux colonnes par côté), les vingt-quatre broches de
  chaque décodeur et les broches des trois amplificateurs échappées
  sous leur boîtier, l'étage de sortie et la résistance du rail
  d'impulsion ramenés dans la zone de liaison, U2 tourné pour que ses
  sorties partent du côté des grilles, la voie de grille des cellules
  sur la face arrière, le budget du routeur triplé, et un rip-up qui
  cherche le mur avec le routeur lui-même au lieu de soulever les
  voisins des pastilles.
- Vingt-quatre builds de quarante à quatre-vingts minutes, quatre à la
  fois : 47 nets ouverts au départ, 39, 43, 38, 30, 23, 23, 27, 25, 26
  (les variantes et leur sens dans la note 04). U3 en tête de zone et
  les ordres de routage « longs d'abord » font pire. Le build commité
  (q44x) laisse 24 nets ouverts et 31 éléments non connectés au DRC.
- Le palier est mesuré : dans les rangées de la dernière cellule de la
  bande 0 et sous les décodeurs, il y a à peu près autant de voies que
  de lignes à faire passer, et un routeur séquentiel n'emplit pas un
  couloir. Le rip-up trouve le mur (deux à cinq nets) et une levée sur
  deux est défaite faute de place pour les nets soulevés. Ce qui reste
  est une décision de conception : autoroutes dessinées à la main pour
  les cellules lointaines (un à deux jours, sans certitude), bande de
  24 mm, six couches, ou cellule allégée.

## 07/10/2026, le pilote simple : la carte bobines passive

- Demande : un pilote au minimum de composants, dans le palier
  100 x 100, une seule carte à concevoir, le traitement sur un shield
  soudé à la main à côté de la Nucleo. C'est la maquette de l'ADR 0008
  sans ses LED : la carte bobines de `coilgen` redevient la carte à
  commander.
- Sans les LED, les 251 violations de la carte tombent à seize, toutes
  dues à la bande de masse du connecteur qui passait sur ses pastilles.
  Bande déplacée au bord, repère `J1` rentré, sérigraphie rognée :
  DRC KiCad zéro, zéro liaison ouverte, gerbers et empreinte commités.
  L'interrupteur est dans le yaml (`leds.fitted`), la variante éclairée
  reste disponible et non vérifiée.
- [Fiche du pilote](../bom-pilote.md) : 130 à 195 EUR TTC tout
  compris avec la carte analogique existante soudée à la main (buck et
  isolateur non montés), contre 220 à 283 pour le quadrant 2 x 2 avec
  son frontal embarqué. Le modèle prédit 0,12 à 0,74 V crête sur la
  spirale : la chaîne de gain de l'ADR 0008 saturerait, à mesurer à
  l'oscilloscope avant de souder le shield.

## Où en est la ligne de temps

Phase 0 faite ; la phase 1 (maquette) est conçue mais ne sera pas
construite : le plateau 8 x 8 est engagé directement (ADR 0010), avec
son module plateau, ses bases et son horloge modélisés. Suivent le
générateur de quadrant, le cerveau, l'horloge, puis les mesures.
Voir [l'état](07-etat-et-reste-a-faire.md).

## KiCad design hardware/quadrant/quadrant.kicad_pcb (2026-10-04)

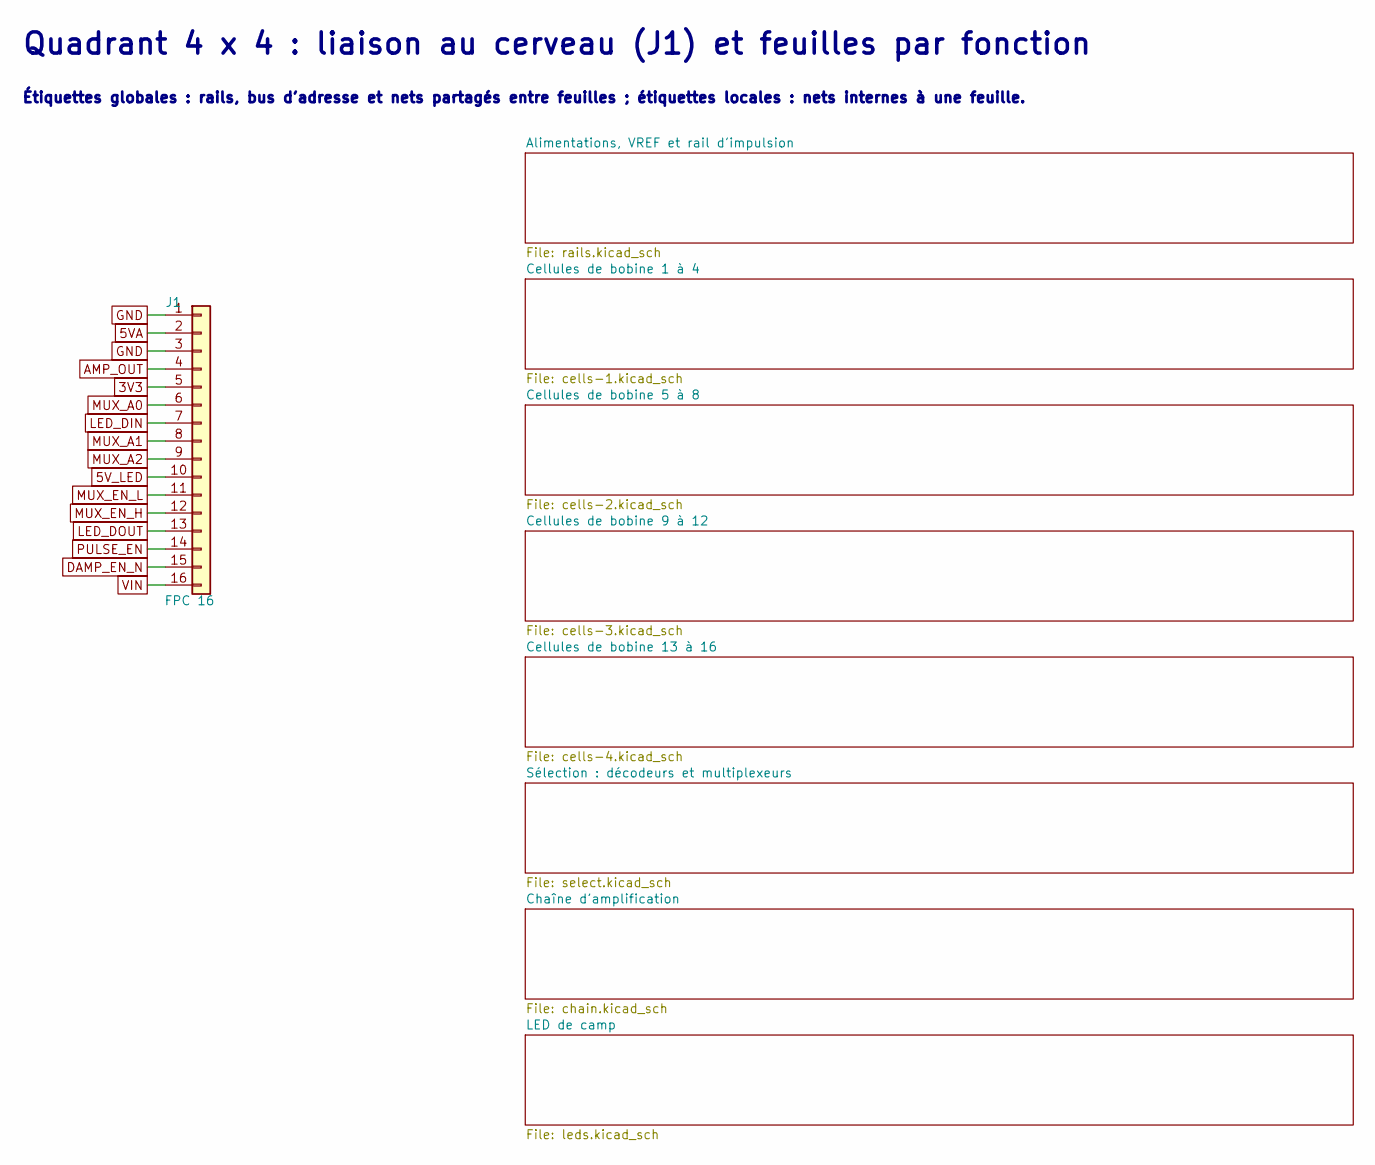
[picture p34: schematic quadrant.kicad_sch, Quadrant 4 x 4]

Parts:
J1: FPC 16; Hirose_FH12-16S-0.5SH_1x16-1MP_P0.50mm_Horizontal; MPN FH12-16S-0.5SH(55); LCSC C2837584

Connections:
3V3: J1.5; also elsewhere on the board
5VA: J1.2; also elsewhere on the board
5V_LED: J1.10; also elsewhere on the board
AMP_OUT: J1.4; also elsewhere on the board
DAMP_EN_N: J1.15; also elsewhere on the board
GND: J1.1, J1.3, J1.MP; also elsewhere on the board
LED_DIN: J1.7; also elsewhere on the board
LED_DOUT: J1.13; also elsewhere on the board
MUX_A0: J1.6; also elsewhere on the board
MUX_A1: J1.8; also elsewhere on the board
MUX_A2: J1.9; also elsewhere on the board
MUX_EN_H: J1.12; also elsewhere on the board
MUX_EN_L: J1.11; also elsewhere on the board
PULSE_EN: J1.14; also elsewhere on the board
VIN: J1.16; also elsewhere on the board

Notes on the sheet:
Quadrant 4 x 4 : liaison au cerveau (J1) et feuilles par fonction
Étiquettes globales : rails, bus d'adresse et nets partagés entre feuilles ; étiquettes locales : nets internes à une feuille.

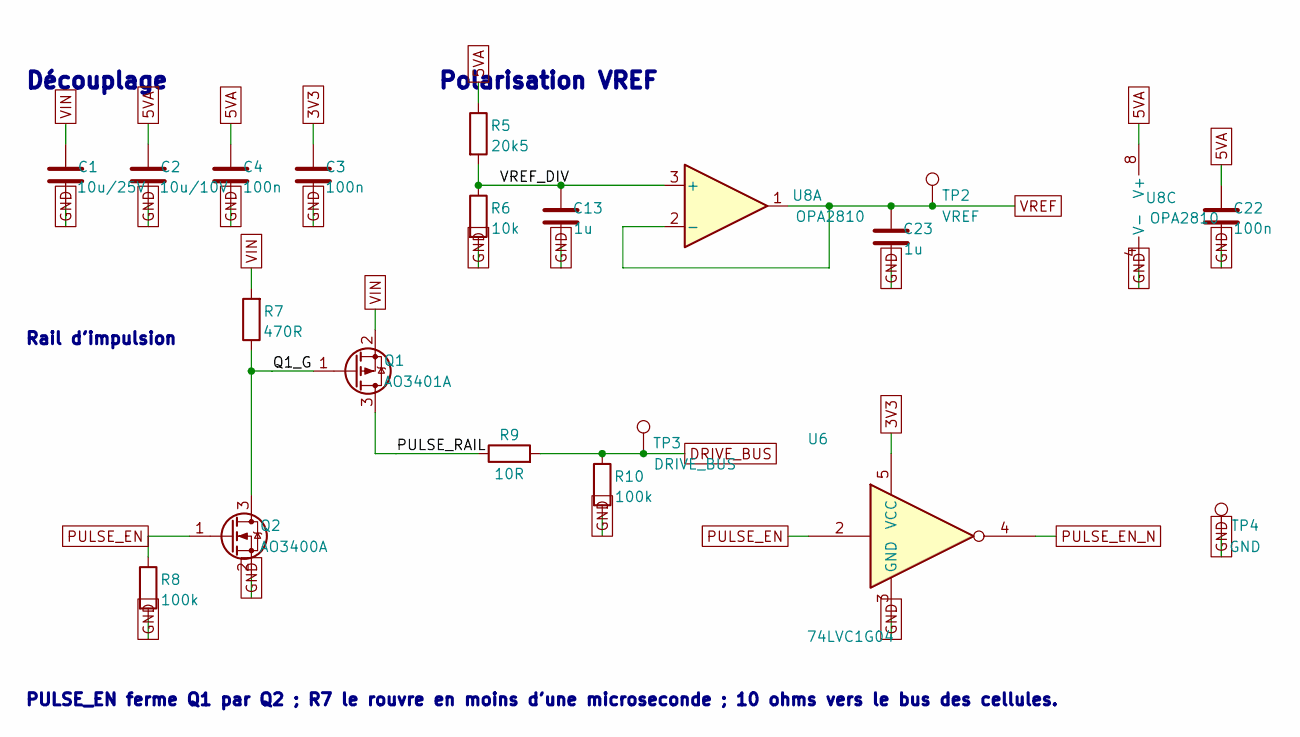
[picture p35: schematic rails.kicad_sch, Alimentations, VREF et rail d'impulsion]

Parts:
C1: 10u/25V; C_1206_3216Metric
C2: 10u/10V; C_1206_3216Metric
C3, C4, C22: 100n; C_0603_1608Metric
C13, C23: 1u; C_0603_1608Metric
Q1: AO3401A; SOT-23; MPN AO3401A; LCSC C15127
Q2: AO3400A; SOT-23; MPN AO3400A; LCSC C20917
R5: 20k5; R_0603_1608Metric
R6: 10k; R_0603_1608Metric
R7: 470R; R_0603_1608Metric
R8, R10: 100k; R_0603_1608Metric
R9: 10R; R_2010_5025Metric
TP2: VREF; TestPoint_Pad_1.5x1.5mm
TP3: DRIVE_BUS; TestPoint_Pad_1.5x1.5mm
TP4: GND; TestPoint_Pad_1.5x1.5mm
U6: 74LVC1G04; SOT-23-5; MPN SN74LVC1G04DBVR; LCSC C7477
U8: OPA2810; SOIC-8_3.9x4.9mm_P1.27mm; MPN OPA2810IDR; LCSC C2059830

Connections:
3V3: C3.1, U6.5 (VCC); also elsewhere on the board
5VA: C2.1, C4.1, C22.1, R5.1, U8.8 (V+); also elsewhere on the board
DRIVE_BUS: R9.2, R10.1, TP3.1; also elsewhere on the board
GND: C1.2, C2.2, C3.2, C4.2, C13.2, C22.2, C23.2, Q2.2 (S), R6.2, R8.2, R10.2, TP4.1, U6.3 (GND), U8.4 (V-); also elsewhere on the board
PULSE_EN: Q2.1 (G), R8.1, U6.2; also elsewhere on the board
PULSE_EN_N: U6.4; also elsewhere on the board
PULSE_RAIL: Q1.3 (D), R9.1
Q1_G: Q1.1 (G), Q2.3 (D), R7.1
VIN: C1.1, Q1.2 (S), R7.2; also elsewhere on the board
VREF: C23.1, TP2.1, U8.1, U8.2 (-); also elsewhere on the board
VREF_DIV: C13.1, R5.2, R6.1, U8.3 (+)

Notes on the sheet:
Découplage
Polarisation VREF
Rail d'impulsion
PULSE_EN ferme Q1 par Q2 ; R7 le rouvre en moins d'une microseconde ; 10 ohms vers le bus des cellules.

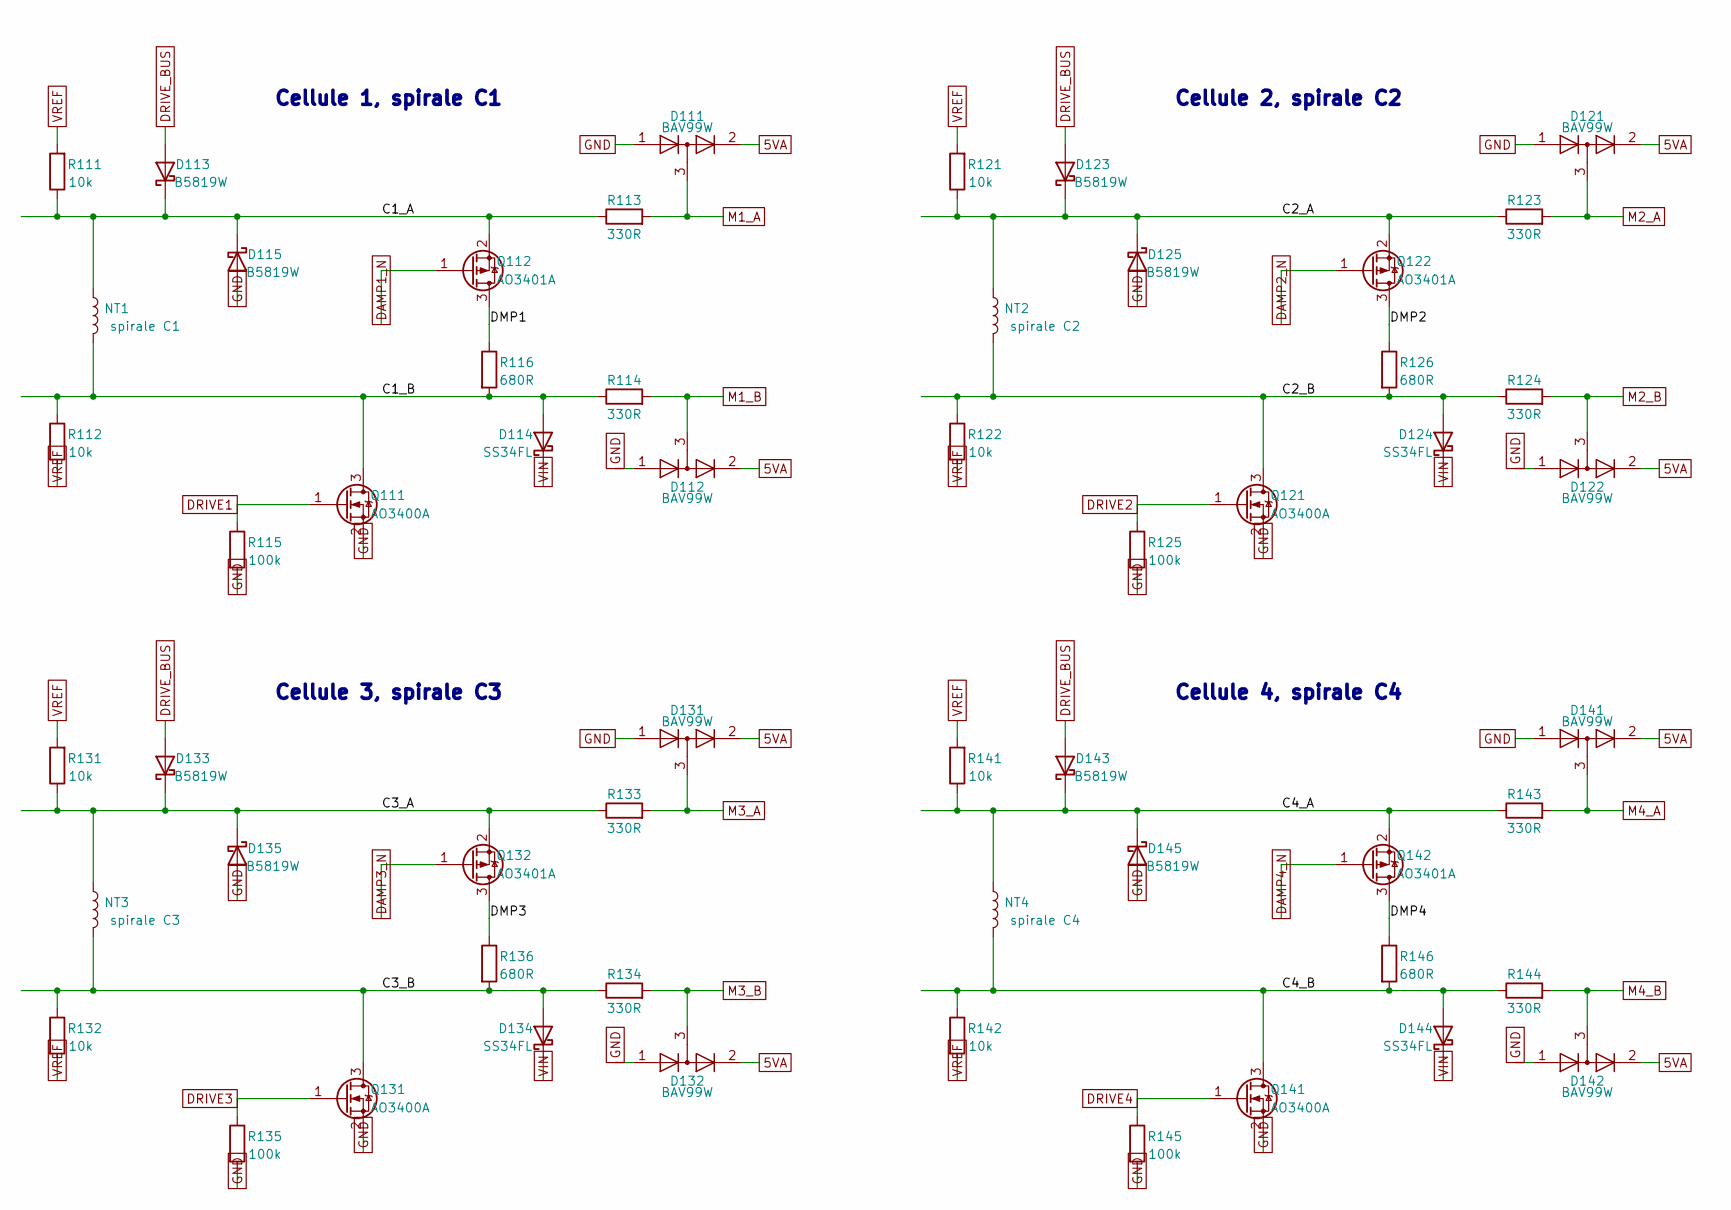
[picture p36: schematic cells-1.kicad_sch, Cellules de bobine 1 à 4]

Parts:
D111, D112, D121, D122, D131, D132, D141, D142: BAV99W; SOT-323_SC-70; MPN BAV99W
D113, D115, D123, D125, D133, D135, D143, D145: B5819W; D_SOD-123; MPN B5819W; LCSC C8598
D114, D124, D134, D144: SS34FL; D_SOD-123F; MPN SS34FL; LCSC C2480216
NT1: spirale C1; COIL_TIE
NT2: spirale C2; COIL_TIE
NT3: spirale C3; COIL_TIE
NT4: spirale C4; COIL_TIE
Q111, Q121, Q131, Q141: AO3400A; SOT-23; MPN AO3400A; LCSC C20917
Q112, Q122, Q132, Q142: AO3401A; SOT-23; MPN AO3401A; LCSC C15127
R111, R112, R121, R122, R131, R132, R141, R142: 10k; R_0603_1608Metric
R113, R114, R123, R124, R133, R134, R143, R144: 330R; R_0603_1608Metric
R115, R125, R135, R145: 100k; R_0402_1005Metric
R116, R126, R136, R146: 680R; R_0805_2012Metric

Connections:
5VA: D111.2 (A), D112.2 (A), D121.2 (A), D122.2 (A), D131.2 (A), D132.2 (A), D141.2 (A), D142.2 (A); also elsewhere on the board
C1_A: D113.1 (K), D115.1 (K), NT1.1, Q112.2 (S), R111.1, R113.1
C1_B: D114.2 (A), NT1.2, Q111.3 (D), R112.1, R114.1, R116.2
C2_A: D123.1 (K), D125.1 (K), NT2.1, Q122.2 (S), R121.1, R123.1
C2_B: D124.2 (A), NT2.2, Q121.3 (D), R122.1, R124.1, R126.2
C3_A: D133.1 (K), D135.1 (K), NT3.1, Q132.2 (S), R131.1, R133.1
C3_B: D134.2 (A), NT3.2, Q131.3 (D), R132.1, R134.1, R136.2
C4_A: D143.1 (K), D145.1 (K), NT4.1, Q142.2 (S), R141.1, R143.1
C4_B: D144.2 (A), NT4.2, Q141.3 (D), R142.1, R144.1, R146.2
DAMP1_N: Q112.1 (G); also elsewhere on the board
DAMP2_N: Q122.1 (G); also elsewhere on the board
DAMP3_N: Q132.1 (G); also elsewhere on the board
DAMP4_N: Q142.1 (G); also elsewhere on the board
DMP1: Q112.3 (D), R116.1
DMP2: Q122.3 (D), R126.1
DMP3: Q132.3 (D), R136.1
DMP4: Q142.3 (D), R146.1
DRIVE1: Q111.1 (G), R115.1; also elsewhere on the board
DRIVE2: Q121.1 (G), R125.1; also elsewhere on the board
DRIVE3: Q131.1 (G), R135.1; also elsewhere on the board
DRIVE4: Q141.1 (G), R145.1; also elsewhere on the board
DRIVE_BUS: D113.2 (A), D123.2 (A), D133.2 (A), D143.2 (A); also elsewhere on the board
GND: D111.1 (K), D112.1 (K), D115.2 (A), D121.1 (K), D122.1 (K), D125.2 (A), D131.1 (K), D132.1 (K), D135.2 (A), D141.1 (K), D142.1 (K), D145.2 (A), Q111.2 (S), Q121.2 (S), Q131.2 (S), Q141.2 (S), R115.2, R125.2, R135.2, R145.2; also elsewhere on the board
M1_A: D111.3 (K), R113.2; also elsewhere on the board
M1_B: D112.3 (K), R114.2; also elsewhere on the board
M2_A: D121.3 (K), R123.2; also elsewhere on the board
M2_B: D122.3 (K), R124.2; also elsewhere on the board
M3_A: D131.3 (K), R133.2; also elsewhere on the board
M3_B: D132.3 (K), R134.2; also elsewhere on the board
M4_A: D141.3 (K), R143.2; also elsewhere on the board
M4_B: D142.3 (K), R144.2; also elsewhere on the board
VIN: D114.1 (K), D124.1 (K), D134.1 (K), D144.1 (K); also elsewhere on the board
VREF: R111.2, R112.2, R121.2, R122.2, R131.2, R132.2, R141.2, R142.2; also elsewhere on the board

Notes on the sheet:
Cellule 1, spirale C1
Cellule 2, spirale C2
Cellule 3, spirale C3
Cellule 4, spirale C4

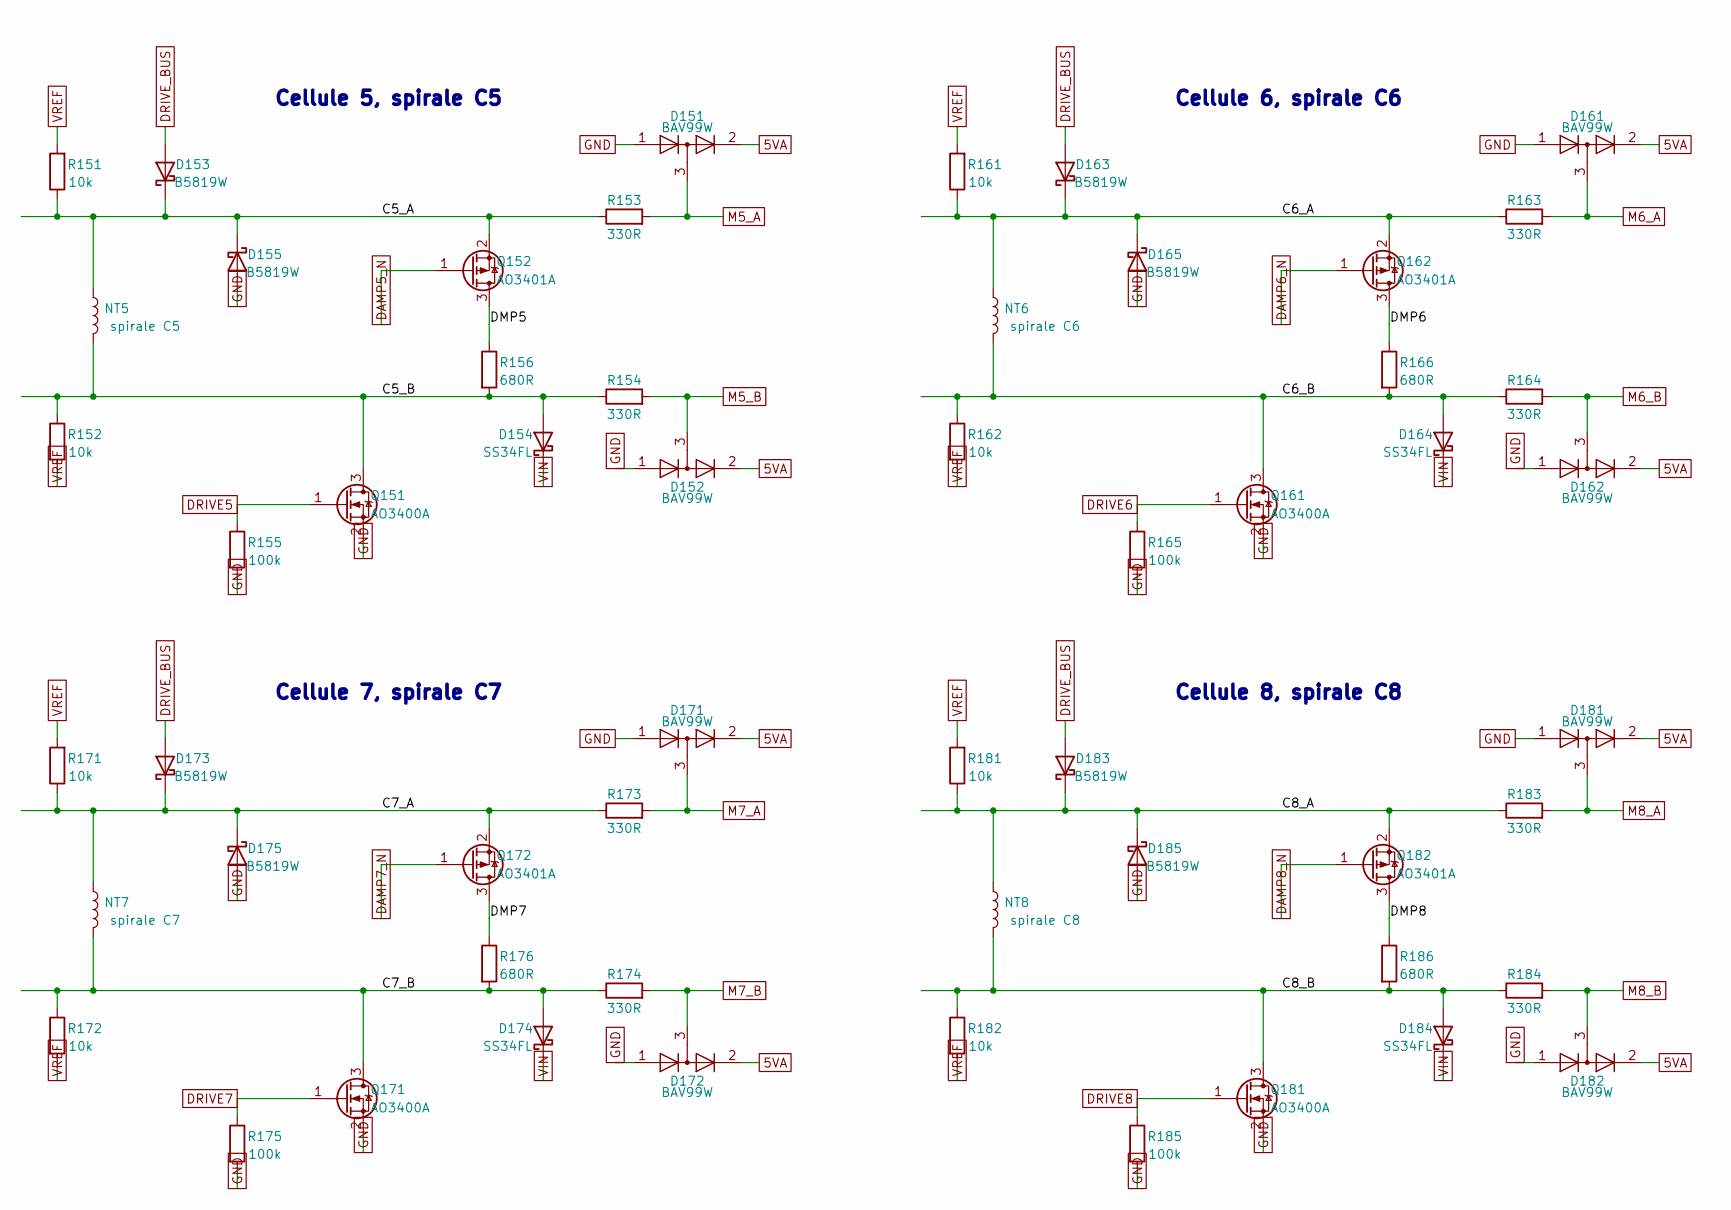
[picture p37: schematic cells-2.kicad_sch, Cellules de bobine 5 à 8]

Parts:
D151, D152, D161, D162, D171, D172, D181, D182: BAV99W; SOT-323_SC-70; MPN BAV99W
D153, D155, D163, D165, D173, D175, D183, D185: B5819W; D_SOD-123; MPN B5819W; LCSC C8598
D154, D164, D174, D184: SS34FL; D_SOD-123F; MPN SS34FL; LCSC C2480216
NT5: spirale C5; COIL_TIE
NT6: spirale C6; COIL_TIE
NT7: spirale C7; COIL_TIE
NT8: spirale C8; COIL_TIE
Q151, Q161, Q171, Q181: AO3400A; SOT-23; MPN AO3400A; LCSC C20917
Q152, Q162, Q172, Q182: AO3401A; SOT-23; MPN AO3401A; LCSC C15127
R151, R152, R161, R162, R171, R172, R181, R182: 10k; R_0603_1608Metric
R153, R154, R163, R164, R173, R174, R183, R184: 330R; R_0603_1608Metric
R155, R165, R175, R185: 100k; R_0402_1005Metric
R156, R166, R176, R186: 680R; R_0805_2012Metric

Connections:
5VA: D151.2 (A), D152.2 (A), D161.2 (A), D162.2 (A), D171.2 (A), D172.2 (A), D181.2 (A), D182.2 (A); also elsewhere on the board
C5_A: D153.1 (K), D155.1 (K), NT5.1, Q152.2 (S), R151.1, R153.1
C5_B: D154.2 (A), NT5.2, Q151.3 (D), R152.1, R154.1, R156.2
C6_A: D163.1 (K), D165.1 (K), NT6.1, Q162.2 (S), R161.1, R163.1
C6_B: D164.2 (A), NT6.2, Q161.3 (D), R162.1, R164.1, R166.2
C7_A: D173.1 (K), D175.1 (K), NT7.1, Q172.2 (S), R171.1, R173.1
C7_B: D174.2 (A), NT7.2, Q171.3 (D), R172.1, R174.1, R176.2
C8_A: D183.1 (K), D185.1 (K), NT8.1, Q182.2 (S), R181.1, R183.1
C8_B: D184.2 (A), NT8.2, Q181.3 (D), R182.1, R184.1, R186.2
DAMP5_N: Q152.1 (G); also elsewhere on the board
DAMP6_N: Q162.1 (G); also elsewhere on the board
DAMP7_N: Q172.1 (G); also elsewhere on the board
DAMP8_N: Q182.1 (G); also elsewhere on the board
DMP5: Q152.3 (D), R156.1
DMP6: Q162.3 (D), R166.1
DMP7: Q172.3 (D), R176.1
DMP8: Q182.3 (D), R186.1
DRIVE5: Q151.1 (G), R155.1; also elsewhere on the board
DRIVE6: Q161.1 (G), R165.1; also elsewhere on the board
DRIVE7: Q171.1 (G), R175.1; also elsewhere on the board
DRIVE8: Q181.1 (G), R185.1; also elsewhere on the board
DRIVE_BUS: D153.2 (A), D163.2 (A), D173.2 (A), D183.2 (A); also elsewhere on the board
GND: D151.1 (K), D152.1 (K), D155.2 (A), D161.1 (K), D162.1 (K), D165.2 (A), D171.1 (K), D172.1 (K), D175.2 (A), D181.1 (K), D182.1 (K), D185.2 (A), Q151.2 (S), Q161.2 (S), Q171.2 (S), Q181.2 (S), R155.2, R165.2, R175.2, R185.2; also elsewhere on the board
M5_A: D151.3 (K), R153.2; also elsewhere on the board
M5_B: D152.3 (K), R154.2; also elsewhere on the board
M6_A: D161.3 (K), R163.2; also elsewhere on the board
M6_B: D162.3 (K), R164.2; also elsewhere on the board
M7_A: D171.3 (K), R173.2; also elsewhere on the board
M7_B: D172.3 (K), R174.2; also elsewhere on the board
M8_A: D181.3 (K), R183.2; also elsewhere on the board
M8_B: D182.3 (K), R184.2; also elsewhere on the board
VIN: D154.1 (K), D164.1 (K), D174.1 (K), D184.1 (K); also elsewhere on the board
VREF: R151.2, R152.2, R161.2, R162.2, R171.2, R172.2, R181.2, R182.2; also elsewhere on the board

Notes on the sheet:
Cellule 5, spirale C5
Cellule 6, spirale C6
Cellule 7, spirale C7
Cellule 8, spirale C8

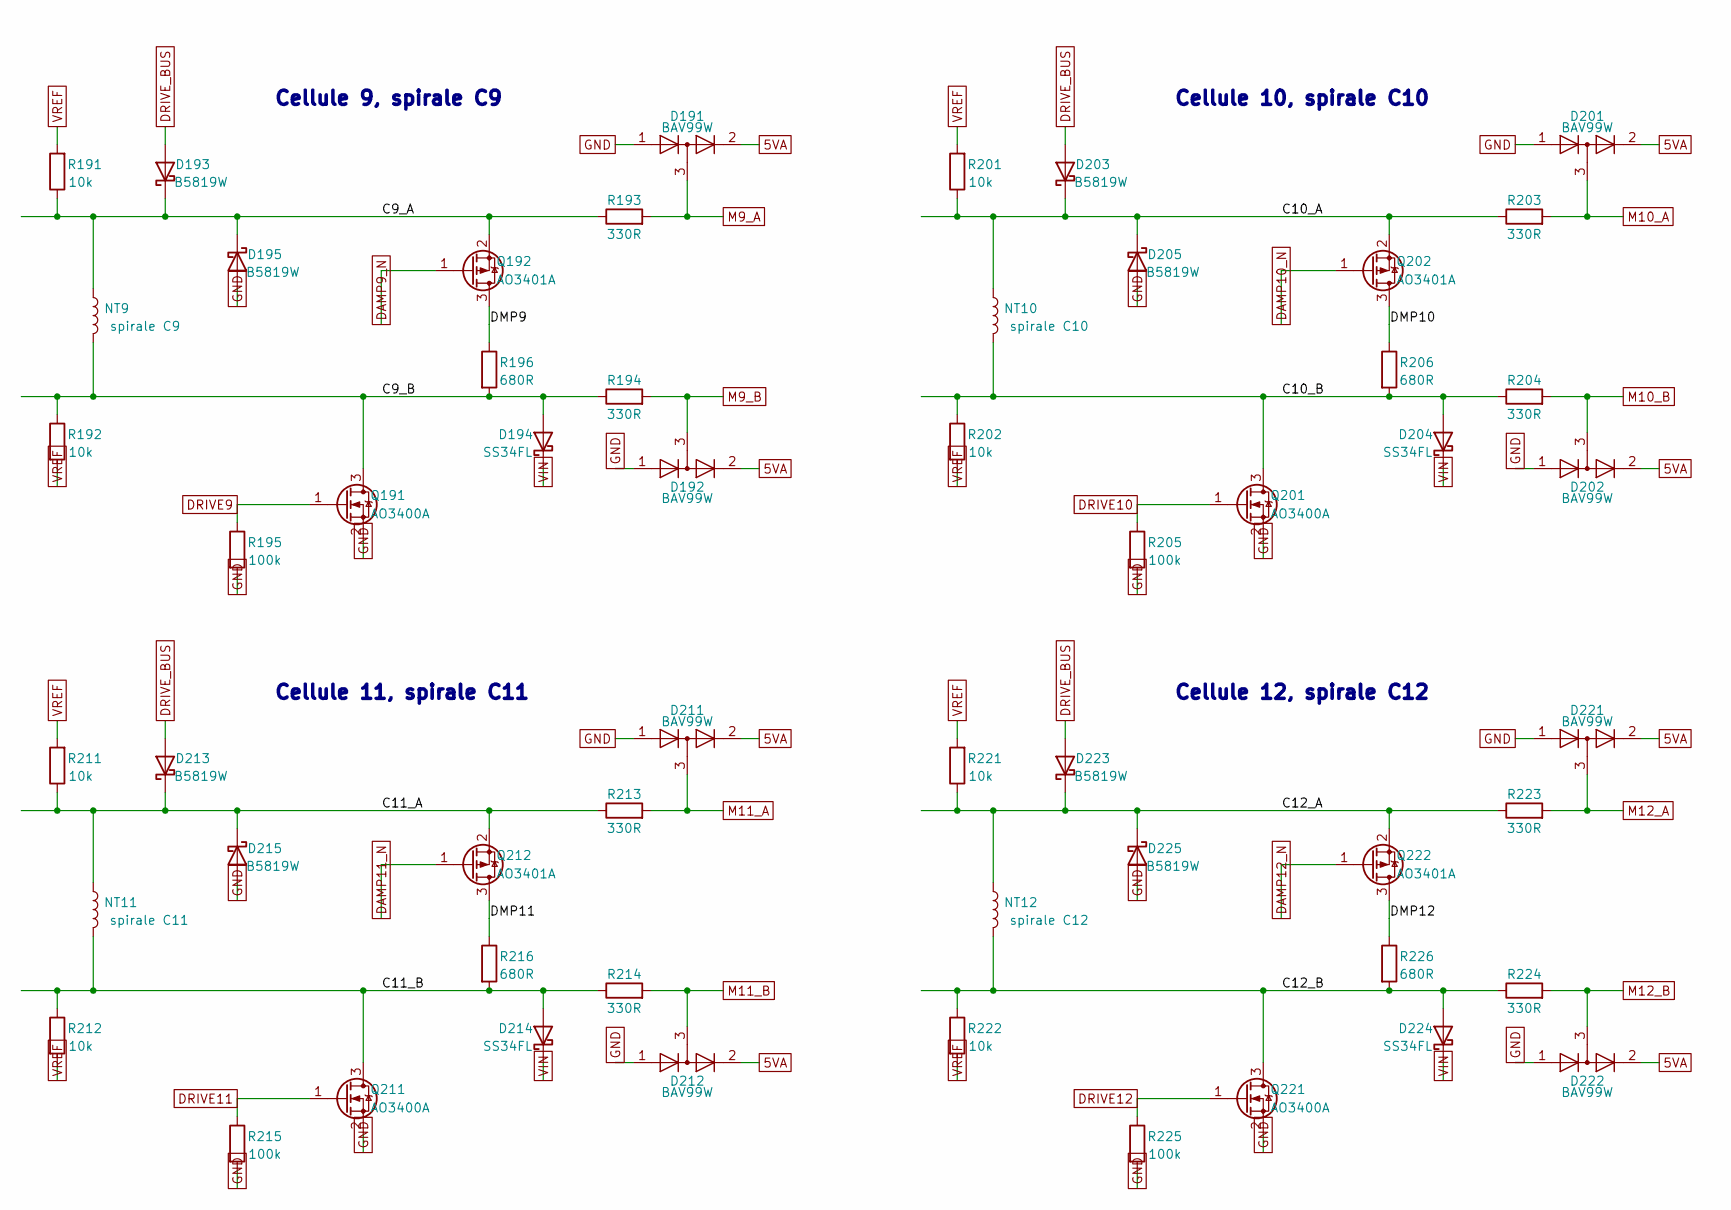
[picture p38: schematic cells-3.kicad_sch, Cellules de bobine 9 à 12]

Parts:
D191, D192, D201, D202, D211, D212, D221, D222: BAV99W; SOT-323_SC-70; MPN BAV99W
D193, D195, D203, D205, D213, D215, D223, D225: B5819W; D_SOD-123; MPN B5819W; LCSC C8598
D194, D204, D214, D224: SS34FL; D_SOD-123F; MPN SS34FL; LCSC C2480216
NT9: spirale C9; COIL_TIE
NT10: spirale C10; COIL_TIE
NT11: spirale C11; COIL_TIE
NT12: spirale C12; COIL_TIE
Q191, Q201, Q211, Q221: AO3400A; SOT-23; MPN AO3400A; LCSC C20917
Q192, Q202, Q212, Q222: AO3401A; SOT-23; MPN AO3401A; LCSC C15127
R191, R192, R201, R202, R211, R212, R221, R222: 10k; R_0603_1608Metric
R193, R194, R203, R204, R213, R214, R223, R224: 330R; R_0603_1608Metric
R195, R205, R215, R225: 100k; R_0402_1005Metric
R196, R206, R216, R226: 680R; R_0805_2012Metric

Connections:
5VA: D191.2 (A), D192.2 (A), D201.2 (A), D202.2 (A), D211.2 (A), D212.2 (A), D221.2 (A), D222.2 (A); also elsewhere on the board
C9_A: D193.1 (K), D195.1 (K), NT9.1, Q192.2 (S), R191.1, R193.1
C9_B: D194.2 (A), NT9.2, Q191.3 (D), R192.1, R194.1, R196.2
C10_A: D203.1 (K), D205.1 (K), NT10.1, Q202.2 (S), R201.1, R203.1
C10_B: D204.2 (A), NT10.2, Q201.3 (D), R202.1, R204.1, R206.2
C11_A: D213.1 (K), D215.1 (K), NT11.1, Q212.2 (S), R211.1, R213.1
C11_B: D214.2 (A), NT11.2, Q211.3 (D), R212.1, R214.1, R216.2
C12_A: D223.1 (K), D225.1 (K), NT12.1, Q222.2 (S), R221.1, R223.1
C12_B: D224.2 (A), NT12.2, Q221.3 (D), R222.1, R224.1, R226.2
DAMP9_N: Q192.1 (G); also elsewhere on the board
DAMP10_N: Q202.1 (G); also elsewhere on the board
DAMP11_N: Q212.1 (G); also elsewhere on the board
DAMP12_N: Q222.1 (G); also elsewhere on the board
DMP9: Q192.3 (D), R196.1
DMP10: Q202.3 (D), R206.1
DMP11: Q212.3 (D), R216.1
DMP12: Q222.3 (D), R226.1
DRIVE9: Q191.1 (G), R195.1; also elsewhere on the board
DRIVE10: Q201.1 (G), R205.1; also elsewhere on the board
DRIVE11: Q211.1 (G), R215.1; also elsewhere on the board
DRIVE12: Q221.1 (G), R225.1; also elsewhere on the board
DRIVE_BUS: D193.2 (A), D203.2 (A), D213.2 (A), D223.2 (A); also elsewhere on the board
GND: D191.1 (K), D192.1 (K), D195.2 (A), D201.1 (K), D202.1 (K), D205.2 (A), D211.1 (K), D212.1 (K), D215.2 (A), D221.1 (K), D222.1 (K), D225.2 (A), Q191.2 (S), Q201.2 (S), Q211.2 (S), Q221.2 (S), R195.2, R205.2, R215.2, R225.2; also elsewhere on the board
M9_A: D191.3 (K), R193.2; also elsewhere on the board
M9_B: D192.3 (K), R194.2; also elsewhere on the board
M10_A: D201.3 (K), R203.2; also elsewhere on the board
M10_B: D202.3 (K), R204.2; also elsewhere on the board
M11_A: D211.3 (K), R213.2; also elsewhere on the board
M11_B: D212.3 (K), R214.2; also elsewhere on the board
M12_A: D221.3 (K), R223.2; also elsewhere on the board
M12_B: D222.3 (K), R224.2; also elsewhere on the board
VIN: D194.1 (K), D204.1 (K), D214.1 (K), D224.1 (K); also elsewhere on the board
VREF: R191.2, R192.2, R201.2, R202.2, R211.2, R212.2, R221.2, R222.2; also elsewhere on the board

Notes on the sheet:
Cellule 9, spirale C9
Cellule 10, spirale C10
Cellule 11, spirale C11
Cellule 12, spirale C12

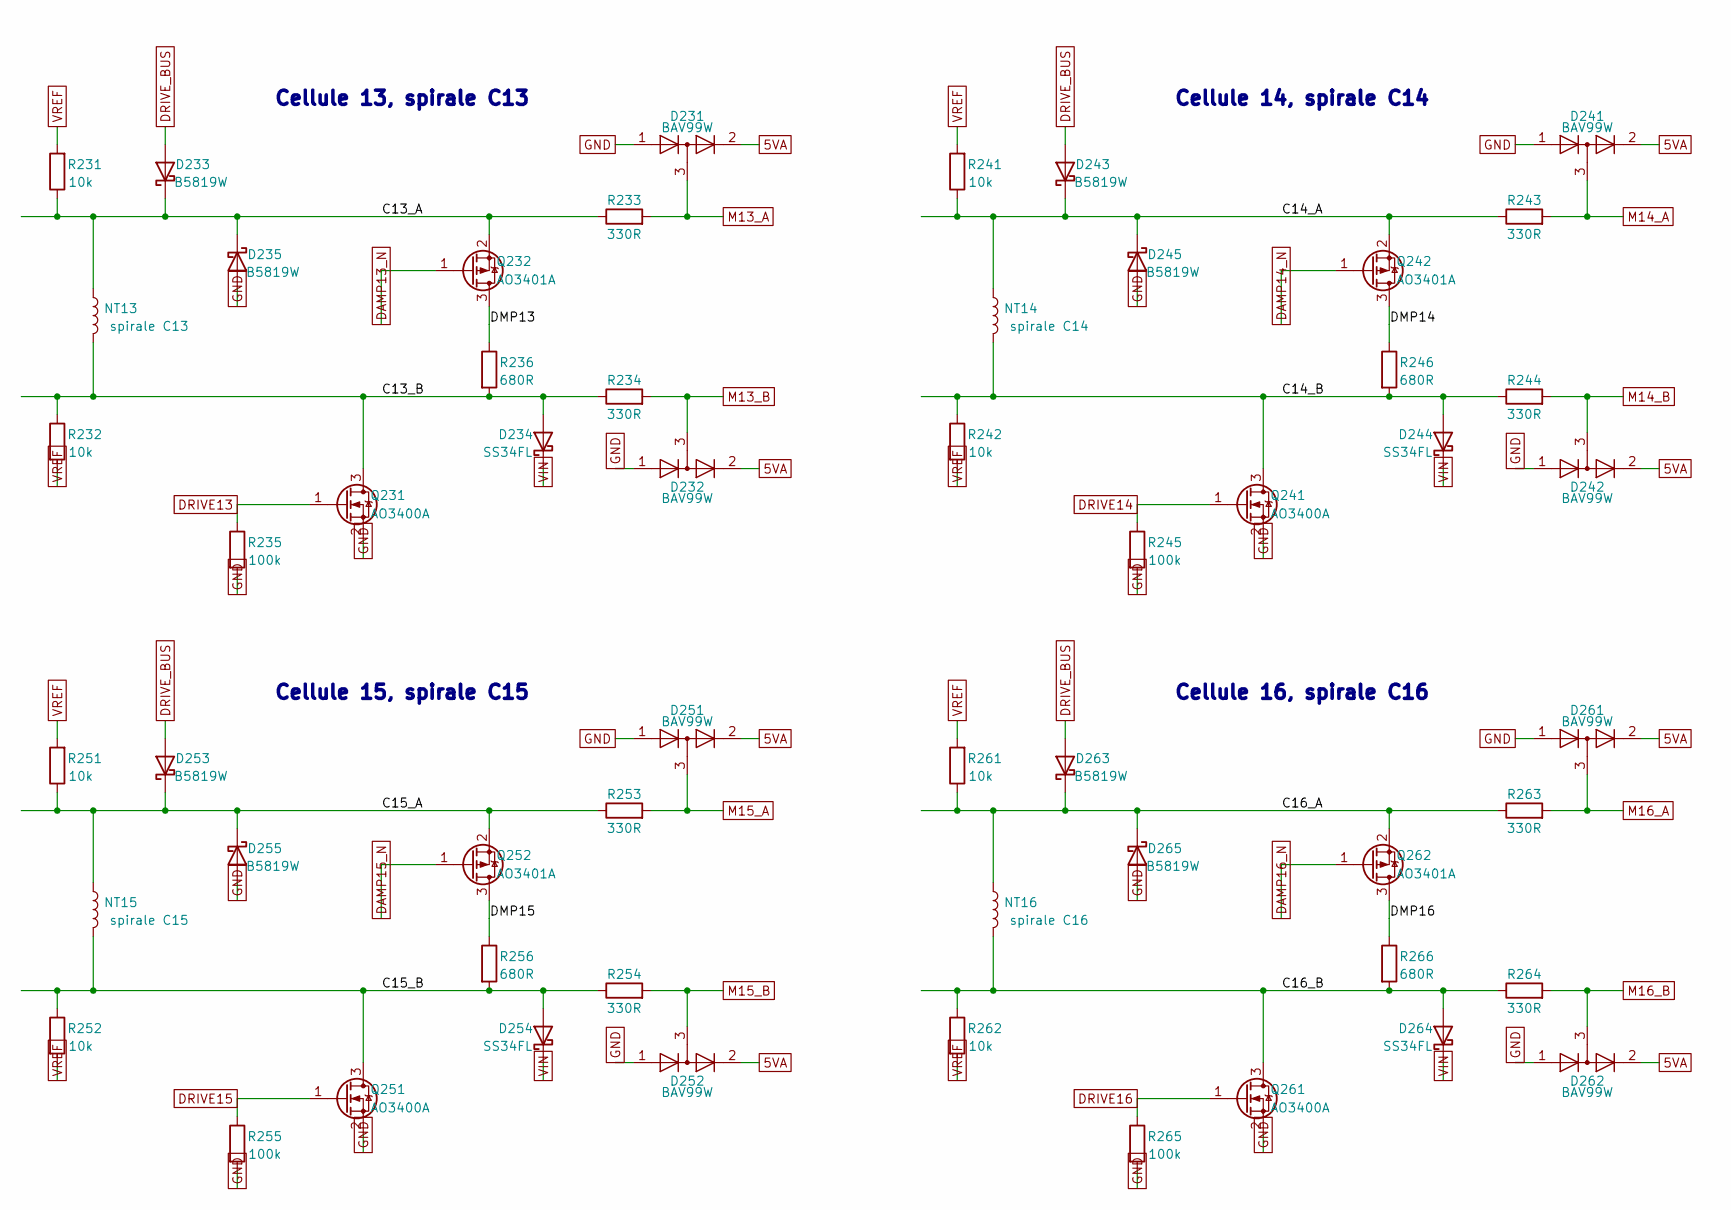
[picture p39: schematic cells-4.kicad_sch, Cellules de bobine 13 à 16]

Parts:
D231, D232, D241, D242, D251, D252, D261, D262: BAV99W; SOT-323_SC-70; MPN BAV99W
D233, D235, D243, D245, D253, D255, D263, D265: B5819W; D_SOD-123; MPN B5819W; LCSC C8598
D234, D244, D254, D264: SS34FL; D_SOD-123F; MPN SS34FL; LCSC C2480216
NT13: spirale C13; COIL_TIE
NT14: spirale C14; COIL_TIE
NT15: spirale C15; COIL_TIE
NT16: spirale C16; COIL_TIE
Q231, Q241, Q251, Q261: AO3400A; SOT-23; MPN AO3400A; LCSC C20917
Q232, Q242, Q252, Q262: AO3401A; SOT-23; MPN AO3401A; LCSC C15127
R231, R232, R241, R242, R251, R252, R261, R262: 10k; R_0603_1608Metric
R233, R234, R243, R244, R253, R254, R263, R264: 330R; R_0603_1608Metric
R235, R245, R255, R265: 100k; R_0402_1005Metric
R236, R246, R256, R266: 680R; R_0805_2012Metric

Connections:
5VA: D231.2 (A), D232.2 (A), D241.2 (A), D242.2 (A), D251.2 (A), D252.2 (A), D261.2 (A), D262.2 (A); also elsewhere on the board
C13_A: D233.1 (K), D235.1 (K), NT13.1, Q232.2 (S), R231.1, R233.1
C13_B: D234.2 (A), NT13.2, Q231.3 (D), R232.1, R234.1, R236.2
C14_A: D243.1 (K), D245.1 (K), NT14.1, Q242.2 (S), R241.1, R243.1
C14_B: D244.2 (A), NT14.2, Q241.3 (D), R242.1, R244.1, R246.2
C15_A: D253.1 (K), D255.1 (K), NT15.1, Q252.2 (S), R251.1, R253.1
C15_B: D254.2 (A), NT15.2, Q251.3 (D), R252.1, R254.1, R256.2
C16_A: D263.1 (K), D265.1 (K), NT16.1, Q262.2 (S), R261.1, R263.1
C16_B: D264.2 (A), NT16.2, Q261.3 (D), R262.1, R264.1, R266.2
DAMP13_N: Q232.1 (G); also elsewhere on the board
DAMP14_N: Q242.1 (G); also elsewhere on the board
DAMP15_N: Q252.1 (G); also elsewhere on the board
DAMP16_N: Q262.1 (G); also elsewhere on the board
DMP13: Q232.3 (D), R236.1
DMP14: Q242.3 (D), R246.1
DMP15: Q252.3 (D), R256.1
DMP16: Q262.3 (D), R266.1
DRIVE13: Q231.1 (G), R235.1; also elsewhere on the board
DRIVE14: Q241.1 (G), R245.1; also elsewhere on the board
DRIVE15: Q251.1 (G), R255.1; also elsewhere on the board
DRIVE16: Q261.1 (G), R265.1; also elsewhere on the board
DRIVE_BUS: D233.2 (A), D243.2 (A), D253.2 (A), D263.2 (A); also elsewhere on the board
GND: D231.1 (K), D232.1 (K), D235.2 (A), D241.1 (K), D242.1 (K), D245.2 (A), D251.1 (K), D252.1 (K), D255.2 (A), D261.1 (K), D262.1 (K), D265.2 (A), Q231.2 (S), Q241.2 (S), Q251.2 (S), Q261.2 (S), R235.2, R245.2, R255.2, R265.2; also elsewhere on the board
M13_A: D231.3 (K), R233.2; also elsewhere on the board
M13_B: D232.3 (K), R234.2; also elsewhere on the board
M14_A: D241.3 (K), R243.2; also elsewhere on the board
M14_B: D242.3 (K), R244.2; also elsewhere on the board
M15_A: D251.3 (K), R253.2; also elsewhere on the board
M15_B: D252.3 (K), R254.2; also elsewhere on the board
M16_A: D261.3 (K), R263.2; also elsewhere on the board
M16_B: D262.3 (K), R264.2; also elsewhere on the board
VIN: D234.1 (K), D244.1 (K), D254.1 (K), D264.1 (K); also elsewhere on the board
VREF: R231.2, R232.2, R241.2, R242.2, R251.2, R252.2, R261.2, R262.2; also elsewhere on the board

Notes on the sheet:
Cellule 13, spirale C13
Cellule 14, spirale C14
Cellule 15, spirale C15
Cellule 16, spirale C16

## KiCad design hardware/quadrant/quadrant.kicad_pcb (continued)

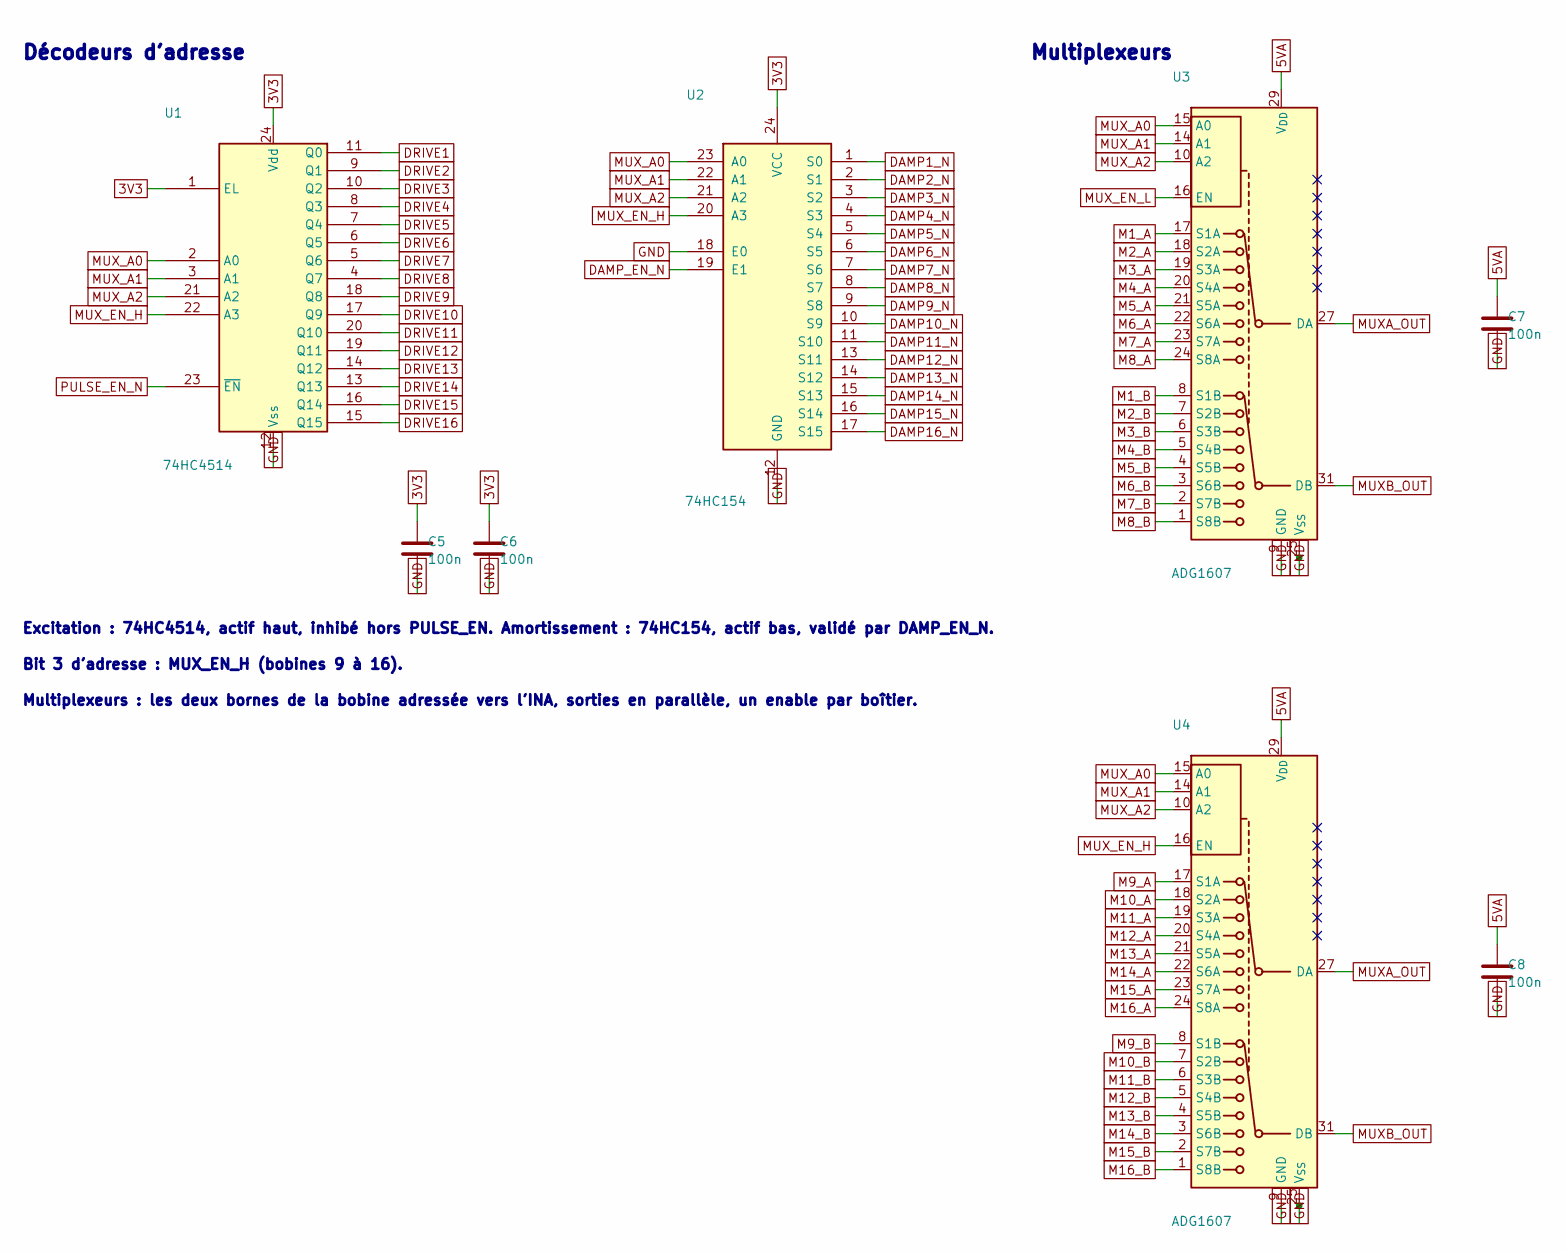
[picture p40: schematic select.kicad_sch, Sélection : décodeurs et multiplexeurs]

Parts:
C5, C6, C7, C8: 100n; C_0603_1608Metric
U1: 74HC4514; TSSOP-24_4.4x7.8mm_P0.65mm; MPN 74HC4514PW; LCSC C5615
U2: 74HC154; TSSOP-24_4.4x7.8mm_P0.65mm; MPN 74HC154PW; LCSC C5613
U3, U4: ADG1607; LFCSP-32-1EP_5x5mm_P0.5mm_EP3.1x3.1mm; MPN ADG1607BCPZ

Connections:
3V3: C5.1, C6.1, U1.1 (EL), U1.24 (Vdd), U2.24 (VCC); also elsewhere on the board
5VA: C7.1, C8.1, U3.29 (V_{DD}), U4.29 (V_{DD}); also elsewhere on the board
DAMP1_N: U2.1 (S0); also elsewhere on the board
DAMP2_N: U2.2 (S1); also elsewhere on the board
DAMP3_N: U2.3 (S2); also elsewhere on the board
DAMP4_N: U2.4 (S3); also elsewhere on the board
DAMP5_N: U2.5 (S4); also elsewhere on the board
DAMP6_N: U2.6 (S5); also elsewhere on the board
DAMP7_N: U2.7 (S6); also elsewhere on the board
DAMP8_N: U2.8 (S7); also elsewhere on the board
DAMP9_N: U2.9 (S8); also elsewhere on the board
DAMP10_N: U2.10 (S9); also elsewhere on the board
DAMP11_N: U2.11 (S10); also elsewhere on the board
DAMP12_N: U2.13 (S11); also elsewhere on the board
DAMP13_N: U2.14 (S12); also elsewhere on the board
DAMP14_N: U2.15 (S13); also elsewhere on the board
DAMP15_N: U2.16 (S14); also elsewhere on the board
DAMP16_N: U2.17 (S15); also elsewhere on the board
DAMP_EN_N: U2.19 (E1); also elsewhere on the board
DRIVE1: U1.11 (Q0); also elsewhere on the board
DRIVE2: U1.9 (Q1); also elsewhere on the board
DRIVE3: U1.10 (Q2); also elsewhere on the board
DRIVE4: U1.8 (Q3); also elsewhere on the board
DRIVE5: U1.7 (Q4); also elsewhere on the board
DRIVE6: U1.6 (Q5); also elsewhere on the board
DRIVE7: U1.5 (Q6); also elsewhere on the board
DRIVE8: U1.4 (Q7); also elsewhere on the board
DRIVE9: U1.18 (Q8); also elsewhere on the board
DRIVE10: U1.17 (Q9); also elsewhere on the board
DRIVE11: U1.20 (Q10); also elsewhere on the board
DRIVE12: U1.19 (Q11); also elsewhere on the board
DRIVE13: U1.14 (Q12); also elsewhere on the board
DRIVE14: U1.13 (Q13); also elsewhere on the board
DRIVE15: U1.16 (Q14); also elsewhere on the board
DRIVE16: U1.15 (Q15); also elsewhere on the board
GND: C5.2, C6.2, C7.2, C8.2, U1.12 (Vss), U2.12 (GND), U2.18 (E0), U3.9 (GND), U3.25 (V_{SS}), U3.33 (V_{SS}), U4.9 (GND), U4.25 (V_{SS}), U4.33 (V_{SS}); also elsewhere on the board
M1_A: U3.17 (S1A); also elsewhere on the board
M1_B: U3.8 (S1B); also elsewhere on the board
M2_A: U3.18 (S2A); also elsewhere on the board
M2_B: U3.7 (S2B); also elsewhere on the board
M3_A: U3.19 (S3A); also elsewhere on the board
M3_B: U3.6 (S3B); also elsewhere on the board
M4_A: U3.20 (S4A); also elsewhere on the board
M4_B: U3.5 (S4B); also elsewhere on the board
M5_A: U3.21 (S5A); also elsewhere on the board
M5_B: U3.4 (S5B); also elsewhere on the board
M6_A: U3.22 (S6A); also elsewhere on the board
M6_B: U3.3 (S6B); also elsewhere on the board
M7_A: U3.23 (S7A); also elsewhere on the board
M7_B: U3.2 (S7B); also elsewhere on the board
M8_A: U3.24 (S8A); also elsewhere on the board
M8_B: U3.1 (S8B); also elsewhere on the board
M9_A: U4.17 (S1A); also elsewhere on the board
M9_B: U4.8 (S1B); also elsewhere on the board
M10_A: U4.18 (S2A); also elsewhere on the board
M10_B: U4.7 (S2B); also elsewhere on the board
M11_A: U4.19 (S3A); also elsewhere on the board
M11_B: U4.6 (S3B); also elsewhere on the board
M12_A: U4.20 (S4A); also elsewhere on the board
M12_B: U4.5 (S4B); also elsewhere on the board
M13_A: U4.21 (S5A); also elsewhere on the board
M13_B: U4.4 (S5B); also elsewhere on the board
M14_A: U4.22 (S6A); also elsewhere on the board
M14_B: U4.3 (S6B); also elsewhere on the board
M15_A: U4.23 (S7A); also elsewhere on the board
M15_B: U4.2 (S7B); also elsewhere on the board
M16_A: U4.24 (S8A); also elsewhere on the board
M16_B: U4.1 (S8B); also elsewhere on the board
MUXA_OUT: U3.27 (DA), U4.27 (DA); also elsewhere on the board
MUXB_OUT: U3.31 (DB), U4.31 (DB); also elsewhere on the board
MUX_A0: U1.2 (A0), U2.23 (A0), U3.15 (A0), U4.15 (A0); also elsewhere on the board
MUX_A1: U1.3 (A1), U2.22 (A1), U3.14 (A1), U4.14 (A1); also elsewhere on the board
MUX_A2: U1.21 (A2), U2.21 (A2), U3.10 (A2), U4.10 (A2); also elsewhere on the board
MUX_EN_H: U1.22 (A3), U2.20 (A3), U4.16 (EN); also elsewhere on the board
MUX_EN_L: U3.16 (EN); also elsewhere on the board
PULSE_EN_N: U1.23 (~EN); also elsewhere on the board

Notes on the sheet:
Décodeurs d'adresse
Excitation : 74HC4514, actif haut, inhibé hors PULSE_EN. Amortissement : 74HC154, actif bas, validé par DAMP_EN_N.
Bit 3 d'adresse : MUX_EN_H (bobines 9 à 16).
Multiplexeurs
Multiplexeurs : les deux bornes de la bobine adressée vers l'INA, sorties en parallèle, un enable par boîtier.

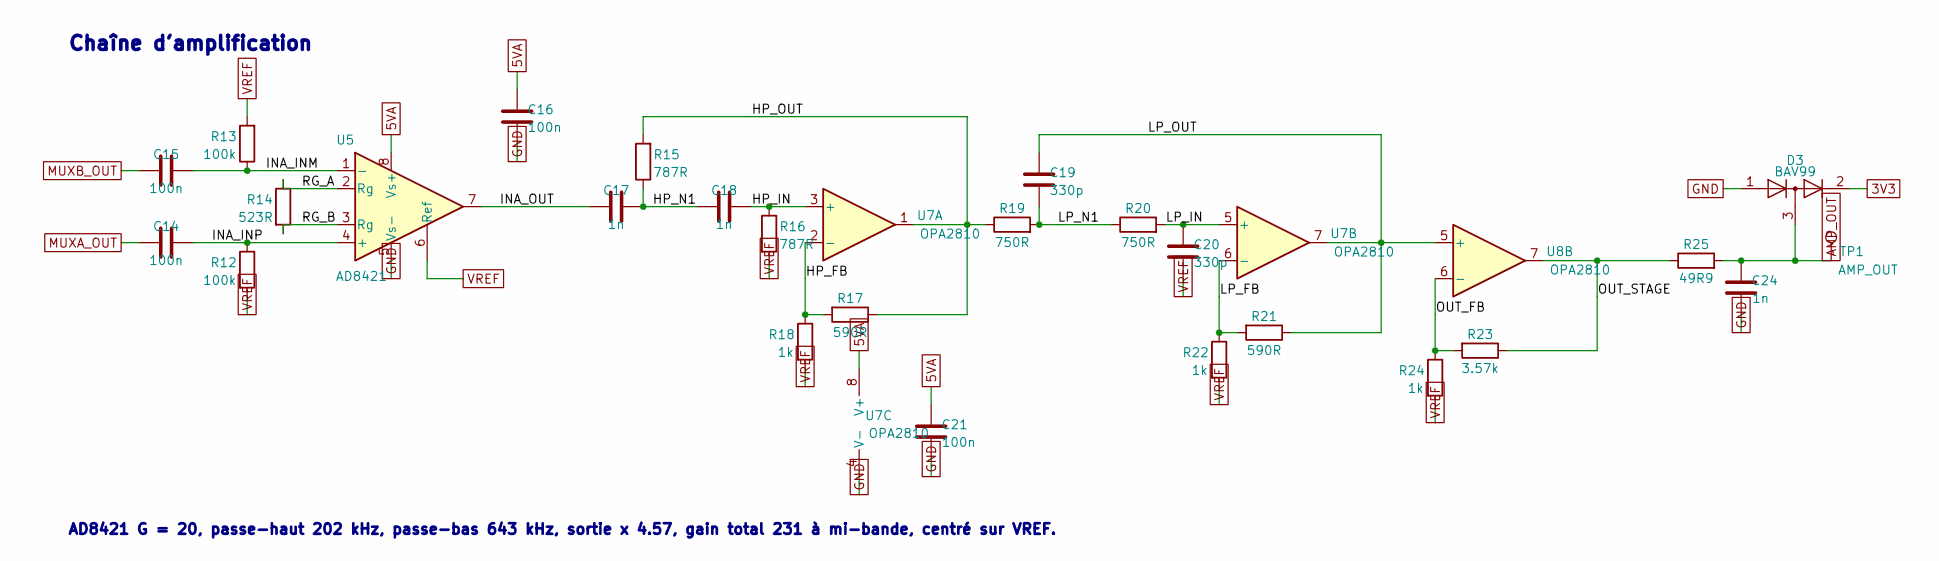
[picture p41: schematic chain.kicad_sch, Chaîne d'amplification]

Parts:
C14, C15, C16, C21: 100n; C_0603_1608Metric
C17, C18, C24: 1n; C_0603_1608Metric
C19, C20: 330p; C_0603_1608Metric
D3: BAV99; SOT-23; MPN BAV99; LCSC C2500
R12, R13: 100k; R_0603_1608Metric
R14: 523R; R_0603_1608Metric
R15, R16: 787R; R_0603_1608Metric
R17, R21: 590R; R_0603_1608Metric
R18, R22, R24: 1k; R_0603_1608Metric
R19, R20: 750R; R_0603_1608Metric
R23: 3.57k; R_0603_1608Metric
R25: 49R9; R_0603_1608Metric
TP1: AMP_OUT; TestPoint_Pad_1.5x1.5mm
U5: AD8421; SOIC-8_3.9x4.9mm_P1.27mm; MPN AD8421ARZ; LCSC C462186
U7, U8: OPA2810; SOIC-8_3.9x4.9mm_P1.27mm; MPN OPA2810IDR; LCSC C2059830

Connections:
3V3: D3.2 (A); also elsewhere on the board
5VA: C16.1, C21.1, U5.8 (Vs+), U7.8 (V+); also elsewhere on the board
AMP_OUT: C24.1, D3.3 (K), R25.2, TP1.1; also elsewhere on the board
GND: C16.2, C21.2, C24.2, D3.1 (K), U5.5 (Vs-), U7.4 (V-); also elsewhere on the board
HP_FB: R17.2, R18.1, U7.2 (-)
HP_IN: C18.2, R16.1, U7.3 (+)
HP_N1: C17.2, C18.1, R15.1
HP_OUT: R15.2, R17.1, R19.1, U7.1
INA_INM: C15.2, R13.1, U5.1 (-)
INA_INP: C14.2, R12.1, U5.4 (+)
INA_OUT: C17.1, U5.7
LP_FB: R21.2, R22.1, U7.6 (-)
LP_IN: C20.1, R20.2, U7.5 (+)
LP_N1: C19.1, R19.2, R20.1
LP_OUT: C19.2, R21.1, U7.7, U8.5 (+)
MUXA_OUT: C14.1; also elsewhere on the board
MUXB_OUT: C15.1; also elsewhere on the board
OUT_FB: R23.2, R24.1, U8.6 (-)
OUT_STAGE: R23.1, R25.1, U8.7
RG_A: R14.1, U5.2 (Rg)
RG_B: R14.2, U5.3 (Rg)
VREF: C20.2, R12.2, R13.2, R16.2, R18.2, R22.2, R24.2, U5.6 (Ref); also elsewhere on the board

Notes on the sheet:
Chaîne d'amplification
AD8421 G = 20, passe-haut 202 kHz, passe-bas 643 kHz, sortie x 4.57, gain total 231 à mi-bande, centré sur VREF.

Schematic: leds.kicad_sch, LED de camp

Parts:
CL1, CL2, CL3, CL4, CL5, CL6, CL7, CL8, CL9, CL10, CL11, CL12, CL13, CL14, CL15, CL16, CL17, CL18, CL19, CL20, CL21, CL22, CL23, CL24, CL25, CL26, CL27, CL28, CL29, CL30, CL31, CL32: 100n; C_0603_1608Metric
LD1, LD2, LD3, LD4, LD5, LD6, LD7, LD8, LD9, LD10, LD11, LD12, LD13, LD14, LD15, LD16, LD17, LD18, LD19, LD20, LD21, LD22, LD23, LD24, LD25, LD26, LD27, LD28, LD29, LD30, LD31, LD32: WS2812B; LED_WS2812B_PLCC4_5.0x5.0mm_P3.2mm; MPN WS2812B; LCSC C2761795

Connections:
5V_LED: CL1.1, CL2.1, CL3.1, CL4.1, CL5.1, CL6.1, CL7.1, CL8.1, CL9.1, CL10.1, CL11.1, CL12.1, CL13.1, CL14.1, CL15.1, CL16.1, CL17.1, CL18.1, CL19.1, CL20.1, CL21.1, CL22.1, CL23.1, CL24.1, CL25.1, CL26.1, CL27.1, CL28.1, CL29.1, CL30.1, CL31.1, CL32.1, LD1.1 (VDD), LD2.1 (VDD), LD3.1 (VDD), LD4.1 (VDD), LD5.1 (VDD), LD6.1 (VDD), LD7.1 (VDD), LD8.1 (VDD), LD9.1 (VDD), LD10.1 (VDD), LD11.1 (VDD), LD12.1 (VDD), LD13.1 (VDD), LD14.1 (VDD), LD15.1 (VDD), LD16.1 (VDD), LD17.1 (VDD), LD18.1 (VDD), LD19.1 (VDD), LD20.1 (VDD), LD21.1 (VDD), LD22.1 (VDD), LD23.1 (VDD), LD24.1 (VDD), LD25.1 (VDD), LD26.1 (VDD), LD27.1 (VDD), LD28.1 (VDD), LD29.1 (VDD), LD30.1 (VDD), LD31.1 (VDD), LD32.1 (VDD); also elsewhere on the board
GND: CL1.2, CL2.2, CL3.2, CL4.2, CL5.2, CL6.2, CL7.2, CL8.2, CL9.2, CL10.2, CL11.2, CL12.2, CL13.2, CL14.2, CL15.2, CL16.2, CL17.2, CL18.2, CL19.2, CL20.2, CL21.2, CL22.2, CL23.2, CL24.2, CL25.2, CL26.2, CL27.2, CL28.2, CL29.2, CL30.2, CL31.2, CL32.2, LD1.3 (VSS), LD2.3 (VSS), LD3.3 (VSS), LD4.3 (VSS), LD5.3 (VSS), LD6.3 (VSS), LD7.3 (VSS), LD8.3 (VSS), LD9.3 (VSS), LD10.3 (VSS), LD11.3 (VSS), LD12.3 (VSS), LD13.3 (VSS), LD14.3 (VSS), LD15.3 (VSS), LD16.3 (VSS), LD17.3 (VSS), LD18.3 (VSS), LD19.3 (VSS), LD20.3 (VSS), LD21.3 (VSS), LD22.3 (VSS), LD23.3 (VSS), LD24.3 (VSS), LD25.3 (VSS), LD26.3 (VSS), LD27.3 (VSS), LD28.3 (VSS), LD29.3 (VSS), LD30.3 (VSS), LD31.3 (VSS), LD32.3 (VSS); also elsewhere on the board
LED_DIN: LD1.4 (DIN); also elsewhere on the board
LED_DOUT: LD32.2 (DOUT); also elsewhere on the board
LED_L1: LD1.2 (DOUT), LD2.4 (DIN)
LED_L2: LD2.2 (DOUT), LD3.4 (DIN)
LED_L3: LD3.2 (DOUT), LD4.4 (DIN)
LED_L4: LD4.2 (DOUT), LD5.4 (DIN)
LED_L5: LD5.2 (DOUT), LD6.4 (DIN)
LED_L6: LD6.2 (DOUT), LD7.4 (DIN)
LED_L7: LD7.2 (DOUT), LD8.4 (DIN)
LED_L8: LD8.2 (DOUT), LD9.4 (DIN)
LED_L9: LD9.2 (DOUT), LD10.4 (DIN)
LED_L10: LD10.2 (DOUT), LD11.4 (DIN)
LED_L11: LD11.2 (DOUT), LD12.4 (DIN)
LED_L12: LD12.2 (DOUT), LD13.4 (DIN)
LED_L13: LD13.2 (DOUT), LD14.4 (DIN)
LED_L14: LD14.2 (DOUT), LD15.4 (DIN)
LED_L15: LD15.2 (DOUT), LD16.4 (DIN)
LED_L16: LD16.2 (DOUT), LD17.4 (DIN)
LED_L17: LD17.2 (DOUT), LD18.4 (DIN)
LED_L18: LD18.2 (DOUT), LD19.4 (DIN)
LED_L19: LD19.2 (DOUT), LD20.4 (DIN)
LED_L20: LD20.2 (DOUT), LD21.4 (DIN)
LED_L21: LD21.2 (DOUT), LD22.4 (DIN)
LED_L22: LD22.2 (DOUT), LD23.4 (DIN)
LED_L23: LD23.2 (DOUT), LD24.4 (DIN)
LED_L24: LD24.2 (DOUT), LD25.4 (DIN)
LED_L25: LD25.2 (DOUT), LD26.4 (DIN)
LED_L26: LD26.2 (DOUT), LD27.4 (DIN)
LED_L27: LD27.2 (DOUT), LD28.4 (DIN)
LED_L28: LD28.2 (DOUT), LD29.4 (DIN)
LED_L29: LD29.2 (DOUT), LD30.4 (DIN)
LED_L30: LD30.2 (DOUT), LD31.4 (DIN)
LED_L31: LD31.2 (DOUT), LD32.4 (DIN)

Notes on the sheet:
LED de camp
WS2812B, deux par case, chaînées dans l'ordre du serpentin des rangées.

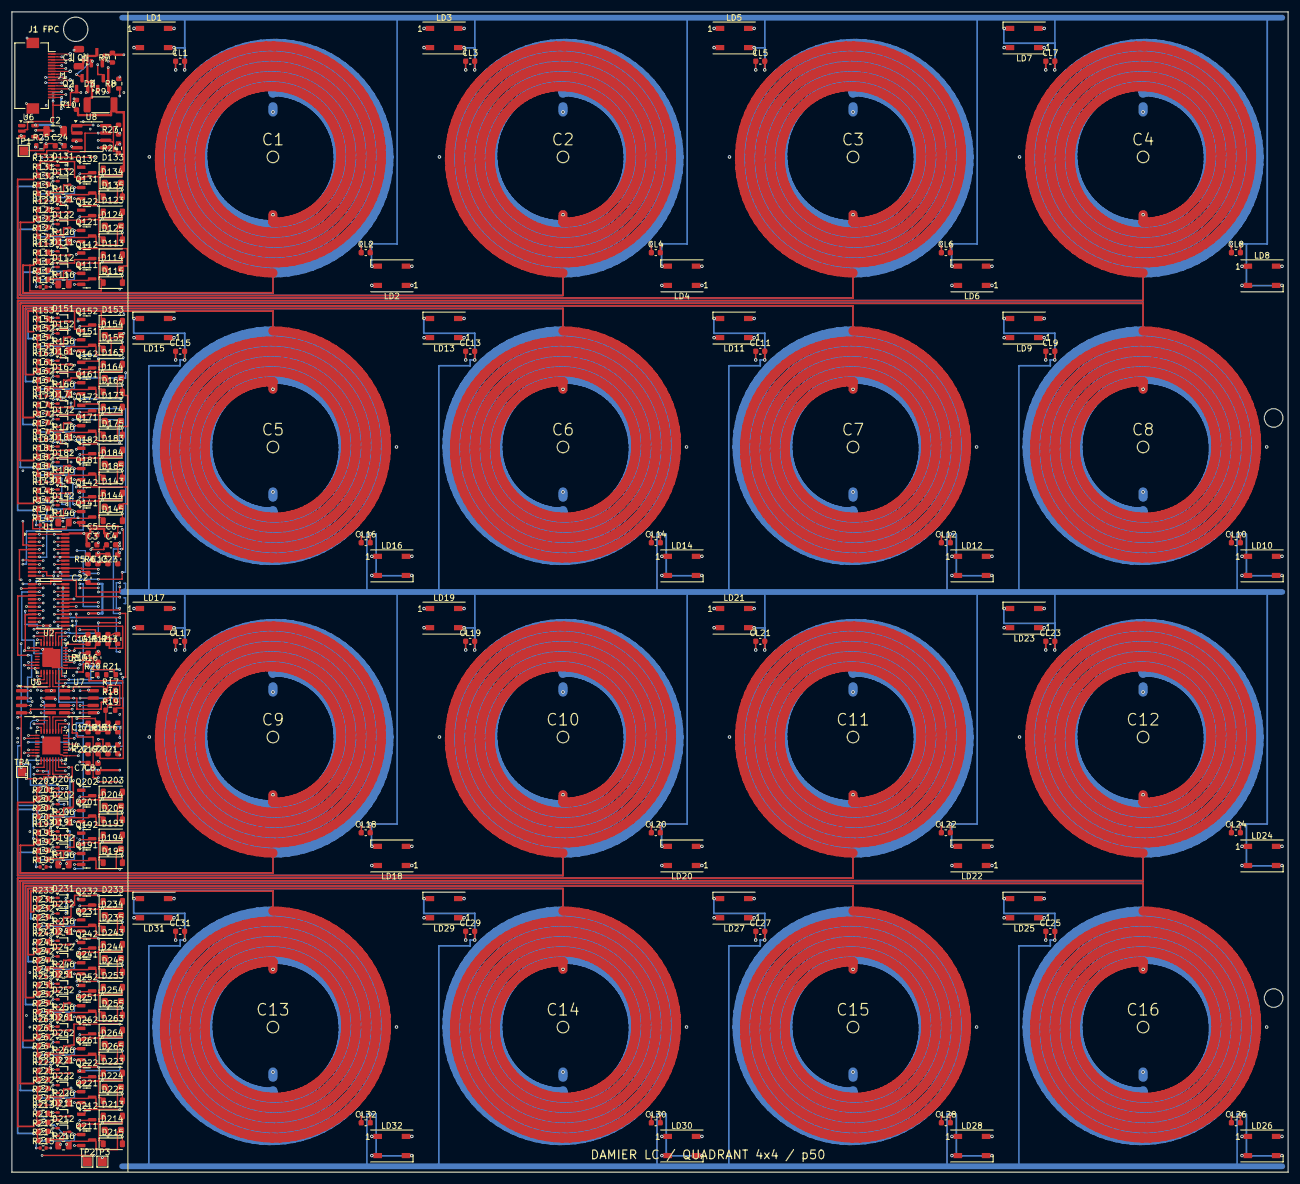
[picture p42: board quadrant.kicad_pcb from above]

Board: 4 copper layers, 220.0 x 200.0 mm, 347 parts (0 on the bottom side), 181 nets.

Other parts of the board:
H1, H2: NPTH; NPTH_3.2
P1: NPTH; NPTH_4.2

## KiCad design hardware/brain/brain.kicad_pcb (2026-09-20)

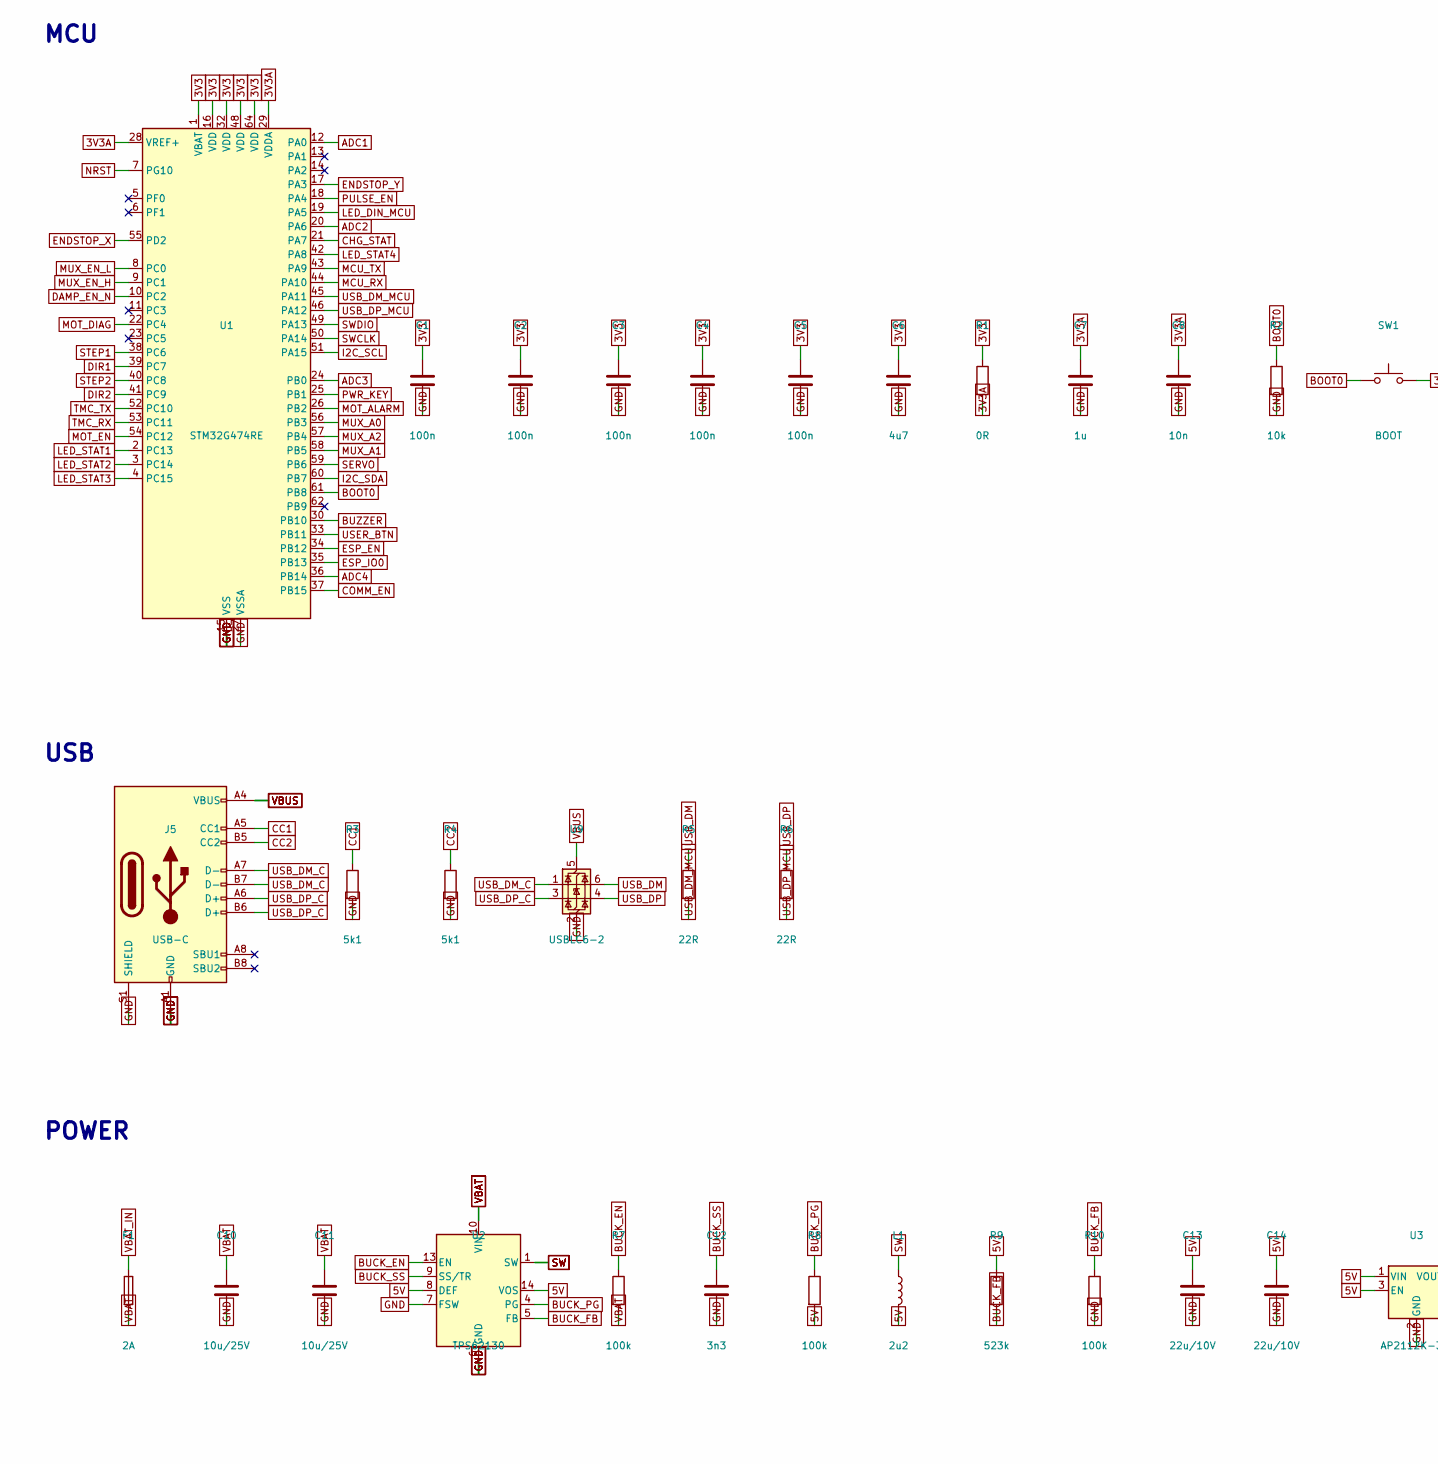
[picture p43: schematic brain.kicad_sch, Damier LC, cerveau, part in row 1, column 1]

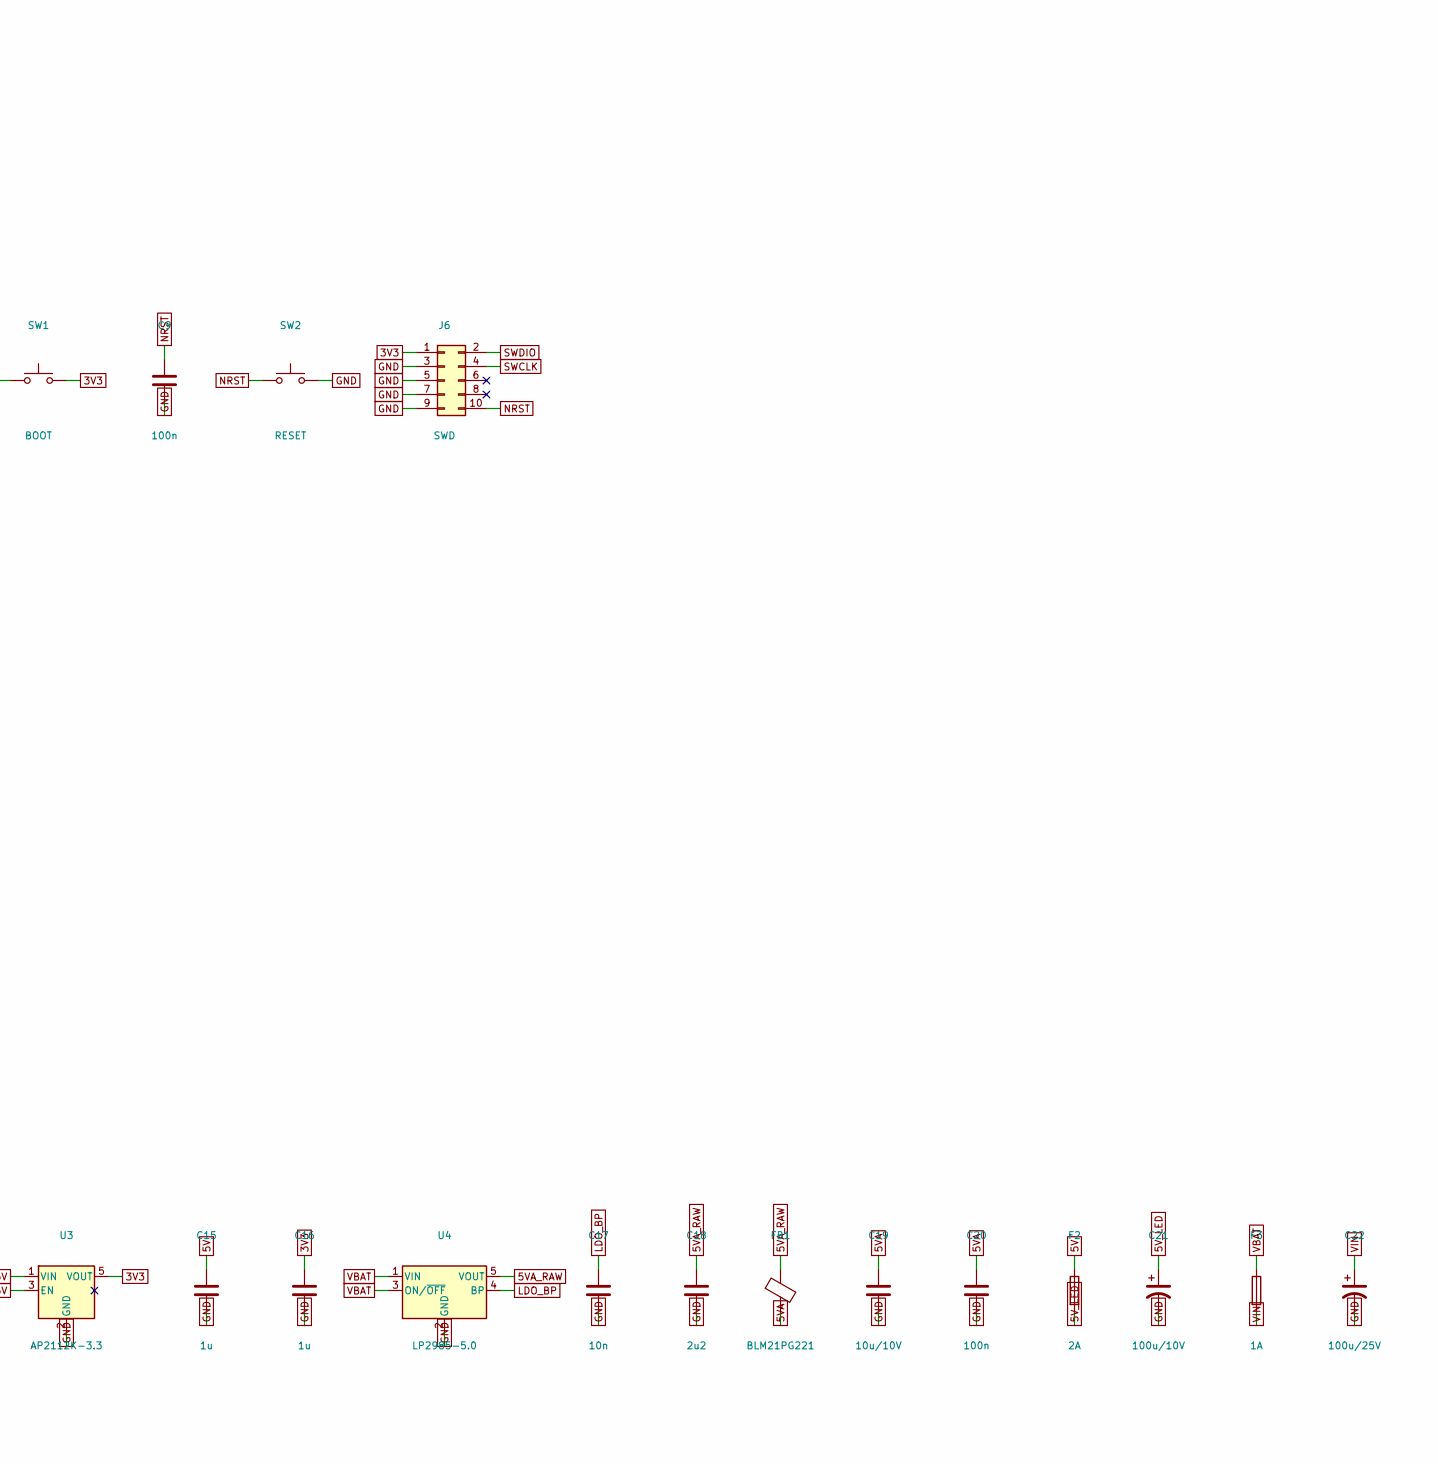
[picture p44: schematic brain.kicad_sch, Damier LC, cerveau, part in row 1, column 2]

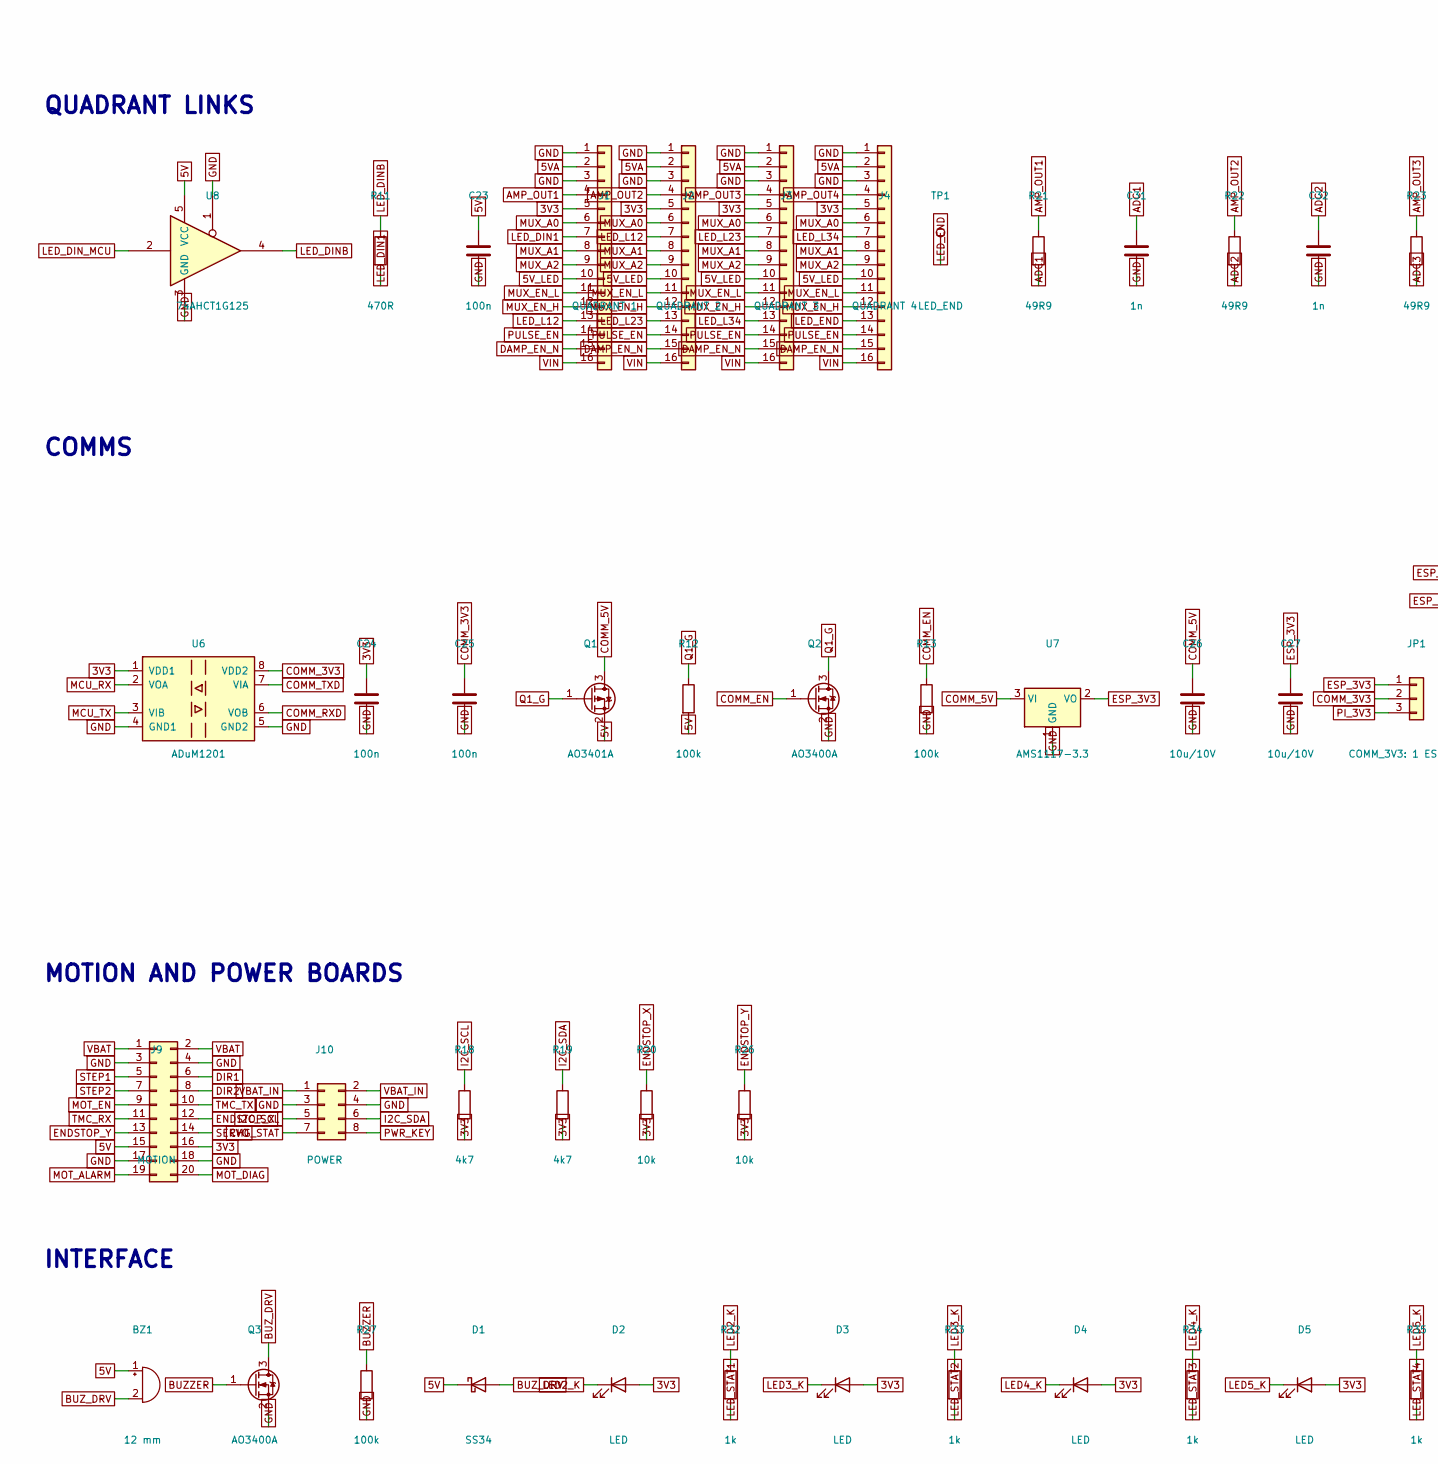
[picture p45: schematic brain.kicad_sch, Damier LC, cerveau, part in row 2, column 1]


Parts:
BZ1: 12 mm; Buzzer_12x9.5RM7.6
C1, C2, C3, C4, C5, C9, C20, C23, C24, C25: 100n; C_0603_1608Metric
C6: 4u7; C_0603_1608Metric
C7, C15, C16, C28: 1u; C_0603_1608Metric
C8, C17: 10n; C_0603_1608Metric
C10, C11: 10u/25V; C_1206_3216Metric
C12: 3n3; C_0603_1608Metric
C13, C14: 22u/10V; C_1206_3216Metric
C18: 2u2; C_0603_1608Metric
C19, C26, C27: 10u/10V; C_1206_3216Metric
C21: 100u/10V; CP_Elec_6.3x7.7
C22: 100u/25V; CP_Elec_6.3x7.7
C31, C32, C33, C34: 1n; C_0603_1608Metric
D1: SS34; D_SMA; MPN SS34; LCSC C8678
D2, D3, D4, D5: LED; LED_0603_1608Metric; MPN 19-217/GHC-YR1S2/3T; LCSC C72043
D6: BAV99; SOT-23; MPN BAV99; LCSC C2500
F1, F2: 2A; Fuse_1206_3216Metric
F3: 1A; Fuse_1206_3216Metric
FB1: BLM21PG221; R_0805_2012Metric; MPN BLM21PG221SN1D; LCSC C18305
H1, H2, H3, H4: M3; MountingHole_3.2mm_M3_Pad
J1: QUADRANT 1; Hirose_FH12-16S-0.5SH_1x16-1MP_P0.50mm_Horizontal; MPN FH12-16S-0.5SH(55); LCSC C2837584
J2: QUADRANT 2; Hirose_FH12-16S-0.5SH_1x16-1MP_P0.50mm_Horizontal; MPN FH12-16S-0.5SH(55); LCSC C2837584
J3: QUADRANT 3; Hirose_FH12-16S-0.5SH_1x16-1MP_P0.50mm_Horizontal; MPN FH12-16S-0.5SH(55); LCSC C2837584
J4: QUADRANT 4; Hirose_FH12-16S-0.5SH_1x16-1MP_P0.50mm_Horizontal; MPN FH12-16S-0.5SH(55); LCSC C2837584
J5: USB-C; USB_C_Receptacle_GCT_USB4085; MPN USB4085-GF-A; LCSC C2988369
J6: SWD; PinHeader_2x05_P1.27mm_Vertical
J7: ESP PROG; PinHeader_1x06_P2.54mm_Vertical
J8: PI ZERO; PinHeader_2x04_P2.54mm_Vertical
J9: MOTION; PinHeader_2x10_P2.54mm_Vertical
J10: POWER; PinHeader_2x04_P2.54mm_Vertical
JP1: COMM_3V3: 1 ESP / 3 PI; PinHeader_1x03_P2.54mm_Vertical
L1: 2u2; L_Bourns_SRN6045TA; MPN SRN6045TA-2R2M; LCSC C167219
Q1: AO3401A; SOT-23; MPN AO3401A; LCSC C15127
Q2, Q3: AO3400A; SOT-23; MPN AO3400A; LCSC C20917
R1, R16, R17: 0R; R_0603_1608Metric
R2, R14, R15, R20, R26, R40: 10k; R_0603_1608Metric
R3, R4: 5k1; R_0603_1608Metric
R5, R6: 22R; R_0603_1608Metric
R7, R8, R10, R12, R13, R27: 100k; R_0603_1608Metric
R9: 523k; R_0603_1608Metric
R11: 470R; R_0603_1608Metric
R18, R19: 4k7; R_0603_1608Metric
R21, R22, R23, R24: 49R9; R_0603_1608Metric
R32, R33, R34, R35: 1k; R_0603_1608Metric
SW1: BOOT; SW_SPST_PTS645; MPN PTS645SM43SMTR92; LCSC C221929
SW2: RESET; SW_SPST_PTS645; MPN PTS645SM43SMTR92; LCSC C221929
SW3: ESP BOOT; SW_SPST_PTS645; MPN PTS645SM43SMTR92; LCSC C221929
SW4: ESP EN; SW_SPST_PTS645; MPN PTS645SM43SMTR92; LCSC C221929
SW5: USER; SW_SPST_PTS645; MPN PTS645SM43SMTR92; LCSC C221929
TP1: LED_END; TestPoint_Pad_1.5x1.5mm
TP2: 5VA; TestPoint_Pad_1.5x1.5mm
TP3: 5V; TestPoint_Pad_1.5x1.5mm
TP4: 3V3; TestPoint_Pad_1.5x1.5mm
TP5: GND; TestPoint_Pad_1.5x1.5mm
TP6: VIN; TestPoint_Pad_1.5x1.5mm
U1: STM32G474RE; LQFP-64_10x10mm_P0.5mm; MPN STM32G474RET6; LCSC C528140
U2: TPS62130; QFN-16-1EP_3x3mm_P0.5mm_EP1.75x1.75mm; MPN TPS62130RGTR; LCSC C74016
U3: AP2112K-3.3; SOT-23-5; MPN AP2112K-3.3TRG1; LCSC C51118
U4: LP2985-5.0; SOT-23-5; MPN LP2985AIM5-5.0; LCSC C129541
U5: ESP32-S3-WROOM-1; MPN ESP32-S3-WROOM-1-N8; LCSC C2913204
U6: ADuM1201; SOIC-8_3.9x4.9mm_P1.27mm; MPN ADuM1201ARZ; LCSC C123211
U7: AMS1117-3.3; SOT-223-3_TabPin2; MPN AMS1117-3.3; LCSC C6186
U8: 74AHCT1G125; SOT-23-5; MPN SN74AHCT1G125DBVR; LCSC C350557
U9: USBLC6-2; SOT-23-6; MPN USBLC6-2SC6; LCSC C7519

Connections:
3V3: C1.1, C2.1, C3.1, C4.1, C5.1, C6.1, C16.1, C24.1, D2.2 (A), D3.2 (A), D4.2 (A), D5.2 (A), D6.2 (A), J1.5, J2.5, J3.5, J4.5, J6.1, J9.16, R1.1, R18.2, R19.2, R20.2, R26.2, R40.2, SW1.2, TP4.1, U1.1 (VBAT), U1.16 (VDD), U1.32 (VDD), U1.48 (VDD), U1.64 (VDD), U3.5 (VOUT), U6.1 (VDD1)
3V3A: C7.1, C8.1, R1.2, U1.28 (VREF+), U1.29 (VDDA)
5V: BZ1.1 (+), C13.1, C14.1, C15.1, C23.1, D1.1 (K), F2.1, J9.15, L1.2, Q1.2 (S), R8.2, R9.1, R12.2, TP3.1, U2.8 (DEF), U2.14 (VOS), U3.1 (VIN), U3.3 (EN), U8.5 (VCC)
5VA: C19.1, C20.1, FB1.2, J1.2, J2.2, J3.2, J4.2, TP2.1
5VA_RAW: C18.1, FB1.1, U4.5 (VOUT)
5V_LED: C21.1, F2.2, J1.10, J2.10, J3.10, J4.10
ADC1: C31.1, R21.2, U1.12 (PA0)
ADC2: C32.1, R22.2, U1.20 (PA6)
ADC3: C33.1, R23.2, U1.24 (PB0)
ADC4: C34.1, R24.2, U1.36 (PB14)
AMP_OUT1: J1.4, R21.1
AMP_OUT2: J2.4, R22.1
AMP_OUT3: J3.4, R23.1
AMP_OUT4: J4.4, R24.1
BOOT0: R2.1, SW1.1, U1.61 (PB8)
BUCK_EN: R7.1, U2.13 (EN)
BUCK_FB: R9.2, R10.1, U2.5 (FB)
BUCK_PG: R8.1, U2.4 (PG)
BUCK_SS: C12.1, U2.9 (SS/TR)
BUZZER: Q3.1 (G), R27.1, U1.30 (PB10)
BUZ_DRV: BZ1.2 (-), D1.2 (A), Q3.3 (D)
CC1: J5.A5 (CC1), R3.1
CC2: J5.B5 (CC2), R4.1
CHG_STAT: J10.7, U1.21 (PA7)
COMM_3V3: C25.1, JP1.2, U6.8 (VDD2)
COMM_5V: C26.1, J8.1, J8.2, Q1.3 (D), U7.3 (VI)
COMM_EN: Q2.1 (G), R13.1, U1.37 (PB15)
COMM_RXD: J8.6, R17.1, U6.6 (VOB)
COMM_TXD: J8.7, R16.2, U6.7 (VIA)
DAMP_EN_N: J1.15, J2.15, J3.15, J4.15, U1.10 (PC2)
DIR1: J9.6, U1.39 (PC7)
DIR2: J9.8, U1.41 (PC9)
ENDSTOP_X: J9.12, R20.1, U1.55 (PD2)
ENDSTOP_Y: J9.13, R26.1, U1.17 (PA3)
ESP_3V3: C27.1, J7.1, JP1.1, R14.2, R15.2, U5.2 (3V3), U7.2 (VO)
ESP_EN: C28.1, J7.3, R14.1, SW4.1, U1.34 (PB12), U5.3 (EN)
ESP_IO0: J7.4, R15.1, SW3.1, U1.35 (PB13), U5.27 (IO0)
ESP_RXD: J7.6, R17.2, U5.36 (RXD0)
ESP_TXD: J7.5, R16.1, U5.37 (TXD0)
GND: C1.2, C2.2, C3.2, C4.2, C5.2, C6.2, C7.2, C8.2, C9.2, C10.2, C11.2, C12.2, C13.2, C14.2, C15.2, C16.2, C17.2, C18.2, C19.2, C20.2, C21.2, C22.2, C23.2, C24.2, C25.2, C26.2, C27.2, C28.2, C31.2, C32.2, C33.2, C34.2, D6.1 (K), H1.1, H2.1, H3.1, H4.1, J1.1, J1.3, J2.1, J2.3, J3.1, J3.3, J4.1, J4.3, J5.A1 (GND), J5.A12 (GND), J5.B1 (GND), J5.B12 (GND), J5.S1 (SHIELD), J6.3, J6.5, J6.7, J6.9, J7.2, J8.3, J8.4, J8.8, J9.3, J9.4, J9.17, J9.18, J10.3, J10.4, Q2.2 (S), Q3.2 (S), R2.2, R3.2, R4.2, R10.2, R13.2, R27.2, SW2.2, SW3.2, SW4.2, SW5.2, TP5.1, U1.15 (VSS), U1.27 (VSSA), U1.31 (VSS), U1.47 (VSS), U1.63 (VSS), U2.6 (GND), U2.7 (FSW), U2.15 (GND), U2.16 (GND), U2.17 (GND), U3.2 (GND), U4.2 (GND), U5.1 (GND), U5.40 (GND), U5.41 (GND), U6.4 (GND1), U6.5 (GND2), U7.1 (GND), U8.1, U8.3 (GND), U9.2 (GND)
I2C_SCL: J10.5, R18.1, U1.51 (PA15)
I2C_SDA: J10.6, R19.1, U1.60 (PB7)
LDO_BP: C17.1, U4.4 (BP)
LED2_K: D2.1 (K), R32.1
LED3_K: D3.1 (K), R33.1
LED4_K: D4.1 (K), R34.1
LED5_K: D5.1 (K), R35.1
LED_DIN1: J1.7, R11.2
LED_DINB: R11.1, U8.4
LED_DIN_MCU: U1.19 (PA5), U8.2
LED_END: J4.13, TP1.1
LED_L12: J1.13, J2.7
LED_L23: J2.13, J3.7
LED_L34: J3.13, J4.7
LED_STAT1: R32.2, U1.2 (PC13)
LED_STAT2: R33.2, U1.3 (PC14)
LED_STAT3: R34.2, U1.4 (PC15)
LED_STAT4: R35.2, U1.42 (PA8)
MCU_RX: U1.44 (PA10), U6.2 (VOA)
MCU_TX: U1.43 (PA9), U6.3 (VIB)
MOT_ALARM: J9.19, U1.26 (PB2)
MOT_DIAG: J9.20, U1.22 (PC4)
MOT_EN: J9.9, U1.54 (PC12)
MUX_A0: J1.6, J2.6, J3.6, J4.6, U1.56 (PB3)
MUX_A1: J1.8, J2.8, J3.8, J4.8, U1.58 (PB5)
MUX_A2: J1.9, J2.9, J3.9, J4.9, U1.57 (PB4)
MUX_EN_H: J1.12, J2.12, J3.12, J4.12, U1.9 (PC1)
MUX_EN_L: J1.11, J2.11, J3.11, J4.11, U1.8 (PC0)
NRST: C9.1, J6.10, SW2.1, U1.7 (PG10)
PI_3V3: J8.5, JP1.3
PULSE_EN: J1.14, J2.14, J3.14, J4.14, U1.18 (PA4)
PWR_KEY: D6.3 (K), J10.8, U1.25 (PB1)
Q1_G: Q1.1 (G), Q2.3 (D), R12.1
SERVO: J9.14, U1.59 (PB6)
STEP1: J9.5, U1.38 (PC6)
STEP2: J9.7, U1.40 (PC8)
SW: L1.1, U2.1 (SW), U2.2 (SW), U2.3 (SW)
SWCLK: J6.4, U1.50 (PA14)
SWDIO: J6.2, U1.49 (PA13)
TMC_RX: J9.11, U1.53 (PC11)
TMC_TX: J9.10, U1.52 (PC10)
USB_DM: R5.1, U9.6 (I/O1)
USB_DM_C: J5.A7 (D-), J5.B7 (D-), U9.1 (I/O1)
USB_DM_MCU: R5.2, U1.45 (PA11)
USB_DP: R6.1, U9.4 (I/O2)
USB_DP_C: J5.A6 (D+), J5.B6 (D+), U9.3 (I/O2)
USB_DP_MCU: R6.2, U1.46 (PA12)
USER_BTN: R40.1, SW5.1, U1.33 (PB11)
VBAT: C10.1, C11.1, F1.2, F3.1, J9.1, J9.2, R7.2, U2.10 (VIN), U2.11 (VIN), U2.12 (VIN), U4.1 (VIN), U4.3 (ON/~OFF)
VBAT_IN: F1.1, J10.1, J10.2
VBUS: J5.A4 (VBUS), J5.A9 (VBUS), J5.B4 (VBUS), J5.B9 (VBUS), U9.5 (VBUS)
VIN: C22.1, F3.2, J1.16, J2.16, J3.16, J4.16, TP6.1

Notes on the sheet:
MCU
USB
POWER
QUADRANT LINKS
COMMS
MOTION AND POWER BOARDS
INTERFACE


Board: 4 copper layers, 120.0 x 80.0 mm, 113 parts (0 on the bottom side), 92 nets.

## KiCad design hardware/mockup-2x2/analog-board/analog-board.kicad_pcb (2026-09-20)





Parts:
C1: 47u/25V; CP_Elec_6.3x7.7
C2: 10u/25V; C_1206_3216Metric
C3, C8, C14, C15, C16, C21, C22, C25, C26, C27: 100n; C_0603_1608Metric
C4: 3n3; C_0603_1608Metric
C5, C6: 22u/10V; C_1206_3216Metric
C7, C12: 10u/10V; C_1206_3216Metric
C9: 10n; C_0603_1608Metric
C10: 2u2; C_0603_1608Metric
C11, C13, C23: 1u; C_0603_1608Metric
C17, C18, C24: 1n; C_0603_1608Metric
C19, C20: 330p; C_0603_1608Metric
D1, D41, D42, D43, D44: SS34; D_SMA; MPN SS34; LCSC C8678
D2: SMBJ15A; D_SMB; MPN SMBJ15A; LCSC C113962
D3, D11, D12, D13, D14, D21, D22, D23, D24: BAV99; SOT-23; MPN BAV99; LCSC C2500
D31, D32, D33, D34: B5819W; D_SOD-123; MPN B5819W; LCSC C8598
FB1: BLM21PG221; R_0805_2012Metric; MPN BLM21PG221SN1D; LCSC C18305
H1, H2, H3, H4: M3; MountingHole_3.2mm_M3_Pad
J1: 12V; BarrelJack_Horizontal; MPN DC-005-5.5x2.1; LCSC C381118
J2: COIL JOINT; PinHeader_1x12_P2.54mm_Vertical
J4: MCU; PinHeader_2x10_P2.54mm_Vertical
J5: PI ZERO; PinHeader_2x04_P2.54mm_Vertical
JP1: 5VA: 1 buck / 3 LDO; PinHeader_1x03_P2.54mm_Vertical
JP3: DEF: 1 PFM / 3 FPWM; PinHeader_1x03_P2.54mm_Vertical
L1: 2u2; L_Bourns-SRN4018; MPN SRN4018TA2R2M; LCSC C2827538
Q1, Q21, Q22, Q23, Q24: AO3401A; SOT-23; MPN AO3401A; LCSC C15127
Q2, Q11, Q12, Q13, Q14: AO3400A; SOT-23; MPN AO3400A; LCSC C20917
R1, R2, R4, R8, R10, R11, R12, R13, R25, R27, R35, R37, R45, R47, R55, R57: 100k; R_0603_1608Metric
R3: 523k; R_0603_1608Metric
R5: 20k5; R_0603_1608Metric
R6, R7, R21, R22, R31, R32, R41, R42, R51, R52: 10k; R_0603_1608Metric
R9: 10R; R_2512_6332Metric
R14: 523R; R_0603_1608Metric
R15, R16: 787R; R_0603_1608Metric
R17, R61: 590R; R_0603_1608Metric
R18, R62, R64: 1k; R_0603_1608Metric
R19, R20: 750R; R_0603_1608Metric
R23, R24, R33, R34, R43, R44, R53, R54: 330R; R_0603_1608Metric
R26, R36, R46, R56: 680R; R_0805_2012Metric
R63: 3.57k; R_0603_1608Metric
R65: 49R9; R_0603_1608Metric
R66, R67: 0R; R_0603_1608Metric; not fitted
R68: 470; R_0603_1608Metric
TP1: INA_OUT; TestPoint_Pad_1.5x1.5mm
TP2: AMP_OUT; TestPoint_Pad_1.5x1.5mm
TP3: VREF; TestPoint_Pad_1.5x1.5mm
TP4: 5VA; TestPoint_Pad_1.5x1.5mm
TP5: GND; TestPoint_Pad_1.5x1.5mm
TP6: DRIVE_BUS; TestPoint_Pad_1.5x1.5mm
U1: TPS62150; QFN-16-1EP_3x3mm_P0.5mm_EP1.75x1.75mm; MPN TPS62150RGTR; LCSC C72631
U2: LP2985-5.0; SOT-23-5; MPN LP2985AIM5-5.0; LCSC C129541
U3: 74HC4052; TSSOP-16_4.4x5mm_P0.65mm; MPN 74HCT4052PW; LCSC C57078
U4: AD8421; SOIC-8_3.9x4.9mm_P1.27mm; MPN AD8421ARZ; LCSC C462186
U5, U6: OPA2810; SOIC-8_3.9x4.9mm_P1.27mm; MPN OPA2810IDR; LCSC C2059830
U7: ADuM1201; SOIC-8_3.9x4.9mm_P1.27mm; MPN ADuM1201ARZ; LCSC C123211
U8: 74AHCT1G125; SOT-23-5; MPN SN74AHCT1G125DBVR; LCSC C350557

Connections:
3V3_NUCLEO: C25.1, D3.2 (A), J4.1, U7.1 (VDD1)
5VA: C12.1, C16.1, C21.1, C22.1, D11.2 (A), D12.2 (A), D13.2 (A), D14.2 (A), D21.2 (A), D22.2 (A), D23.2 (A), D24.2 (A), JP1.2, R5.1, R11.2, TP4.1, U3.16 (VDD), U4.8 (Vs+), U5.8 (V+), U6.8 (V+)
5V_BUCK: C5.1, C6.1, C27.1, FB1.1, J2.12, J5.1, J5.2, JP3.3, L1.2, R2.2, R3.1, U1.14 (VOS), U8.5 (VCC)
5V_BUCK_FILT: C7.1, C8.1, FB1.2, JP1.1
5V_LDO: C10.1, JP1.3, U2.5 (VOUT)
AMP_OUT: C24.1, D3.3 (K), J4.3, R65.2, TP2.1
BUCK_DEF: JP3.2, U1.8 (DEF)
BUCK_EN: R1.1, U1.13 (EN)
BUCK_FB: R3.2, R4.1, U1.5 (FB)
BUCK_PG: R2.1, U1.4 (PG)
BUCK_SS: C4.1, U1.9 (SS/TR)
C1_A: D31.1 (K), J2.2, Q21.2 (S), R21.1, R23.1
C1_B: D41.2 (A), J2.3, Q11.3 (D), R22.1, R24.1, R26.2
C2_A: D32.1 (K), J2.8, Q22.2 (S), R31.1, R33.1
C2_B: D42.2 (A), J2.9, Q12.3 (D), R32.1, R34.1, R36.2
C3_A: D33.1 (K), J2.4, Q23.2 (S), R41.1, R43.1
C3_B: D43.2 (A), J2.5, Q13.3 (D), R42.1, R44.1, R46.2
C4_A: D34.1 (K), J2.6, Q24.2 (S), R51.1, R53.1
C4_B: D44.2 (A), J2.7, Q14.3 (D), R52.1, R54.1, R56.2
DAMP1_N: J4.13, Q21.1 (G), R27.1
DAMP2_N: J4.14, Q22.1 (G), R37.1
DAMP3_N: J4.15, Q23.1 (G), R47.1
DAMP4_N: J4.16, Q24.1 (G), R57.1
DMP1: Q21.3 (D), R26.1
DMP2: Q22.3 (D), R36.1
DMP3: Q23.3 (D), R46.1
DMP4: Q24.3 (D), R56.1
DRIVE1: J4.9, Q11.1 (G), R25.1
DRIVE2: J4.10, Q12.1 (G), R35.1
DRIVE3: J4.11, Q13.1 (G), R45.1
DRIVE4: J4.12, Q14.1 (G), R55.1
DRIVE_BUS: D31.2 (A), D32.2 (A), D33.2 (A), D34.2 (A), R9.2, R10.1, TP6.1
GND: C1.2, C2.2, C3.2, C4.2, C5.2, C6.2, C7.2, C8.2, C9.2, C10.2, C11.2, C12.2, C13.2, C16.2, C21.2, C22.2, C23.2, C24.2, C25.2, C26.2, C27.2, D2.1 (A1), D3.1 (K), D11.1 (K), D12.1 (K), D13.1 (K), D14.1 (K), D21.1 (K), D22.1 (K), D23.1 (K), D24.1 (K), H1.1, H2.1, H3.1, H4.1, J1.2, J1.3, J2.1, J2.10, J4.2, J4.19, J5.3, J5.4, J5.8, JP3.1, Q2.2 (S), Q11.2 (S), Q12.2 (S), Q13.2 (S), Q14.2 (S), R4.2, R6.2, R8.2, R10.2, R25.2, R35.2, R45.2, R55.2, TP5.1, U1.6 (GND), U1.7 (FSW), U1.15 (GND), U1.16 (GND), U1.17 (GND), U2.2 (GND), U3.7 (VEE), U3.8 (VSS), U4.5 (Vs-), U5.4 (V-), U6.4 (V-), U7.4 (GND1), U7.5 (GND2), U8.1, U8.3 (GND)
HP_FB: R17.2, R18.1, U5.2 (-)
HP_IN: C18.2, R16.1, U5.3 (+)
HP_N1: C17.2, C18.1, R15.1
HP_OUT: R15.2, R17.1, R19.1, U5.1
INA_INM: C15.2, R13.1, U4.1 (-)
INA_INP: C14.2, R12.1, U4.4 (+)
INA_OUT: C17.1, J4.20, TP1.1, U4.7
LDO_BP: C9.1, U2.4 (BP)
LED_DIN: J4.4, U8.2
LED_DIN5: J2.11, R68.2
LED_DINB: R68.1, U8.4
LP_FB: R61.2, R62.1, U5.6 (-)
LP_IN: C20.1, R20.2, U5.5 (+)
LP_N1: C19.1, R19.2, R20.1
LP_OUT: C19.2, R61.1, U5.7, U6.5 (+)
M1_A: D11.3 (K), R23.2, U3.12 (X0)
M1_B: D21.3 (K), R24.2, U3.1 (Y0)
M2_A: D12.3 (K), R33.2, U3.14 (X1)
M2_B: D22.3 (K), R34.2, U3.5 (Y1)
M3_A: D13.3 (K), R43.2, U3.15 (X2)
M3_B: D23.3 (K), R44.2, U3.2 (Y2)
M4_A: D14.3 (K), R53.2, U3.11 (X3)
M4_B: D24.3 (K), R54.2, U3.4 (Y3)
MCU_RX: J4.18, R67.2, U7.2 (VOA)
MCU_TX: J4.17, R66.1, U7.3 (VIB)
MUXA_OUT: C14.1, U3.13 (X)
MUXB_OUT: C15.1, U3.3 (Y)
MUX_A0: J4.5, U3.10 (A)
MUX_A1: J4.6, U3.9 (B)
MUX_INH: J4.7, R11.1, U3.6 (Inh)
OUT_FB: R63.2, R64.1, U6.6 (-)
OUT_STAGE: R63.1, R65.1, U6.7
PI_3V3: C26.1, J5.5, U7.8 (VDD2)
PI_RXD: J5.7, R66.2, U7.6 (VOB)
PI_TXD: J5.6, R67.1, U7.7 (VIA)
PULSE_EN: J4.8, Q2.1 (G), R8.1
PULSE_RAIL: Q1.3 (D), R9.1
Q1_G: Q1.1 (G), Q2.3 (D), R7.1
RG_A: R14.1, U4.2 (Rg)
RG_B: R14.2, U4.3 (Rg)
SW: L1.1, U1.1 (SW), U1.2 (SW), U1.3 (SW)
VIN: C1.1, C2.1, C3.1, C11.1, D1.1 (K), D2.2 (A2), D41.1 (K), D42.1 (K), D43.1 (K), D44.1 (K), Q1.2 (S), R1.2, R7.2, R27.2, R37.2, R47.2, R57.2, U1.10 (VIN), U1.11 (VIN), U1.12 (VIN), U2.1 (VIN), U2.3 (ON/~OFF)
VIN_JACK: D1.2 (A), J1.1
VREF: C20.2, C23.1, R12.2, R13.2, R16.2, R18.2, R21.2, R22.2, R31.2, R32.2, R41.2, R42.2, R51.2, R52.2, R62.2, R64.2, TP3.1, U4.6 (Ref), U6.1, U6.2 (-)
VREF_DIV: C13.1, R5.2, R6.1, U6.3 (+)

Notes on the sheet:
POWER
DRIVE RAIL
COIL CELL 1
COIL CELL 2
COIL CELL 3
COIL CELL 4
MUX AND AMPLIFIER
FILTERS AND OUTPUT
UART AND HEADERS
TEST AND MECHANICAL
OTHER


Board: 2 copper layers, 100.0 x 62.0 mm, 138 parts (0 on the bottom side), 78 nets.

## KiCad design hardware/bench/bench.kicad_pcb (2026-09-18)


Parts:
C1: 100u/25V; CP_Elec_6.3x7.7
C2: 10u/25V; C_1206_3216Metric
C3, C11, C12, C14: 100n; C_0603_1608Metric
C4: 3n3; C_0603_1608Metric
C5, C6: 22u/10V; C_1206_3216Metric
C7: 100u/10V; CP_Elec_6.3x7.7
C8: 10n; C_0603_1608Metric
C9: 2u2; C_0603_1608Metric
C10: 10u/10V; C_1206_3216Metric
C13: 1n; C_0603_1608Metric
D1: SS34; D_SMA; MPN SS34; LCSC C8678
D2: SMBJ15A; D_SMB; MPN SMBJ15A; LCSC C113962
F1: 1A; Fuse_1206_3216Metric
F2: 2A; Fuse_1206_3216Metric
FB1: BLM21PG221; R_0805_2012Metric; MPN BLM21PG221SN1D; LCSC C18305
J1: 12V; BarrelJack_Horizontal; MPN DC-005-5.5x2.1; LCSC C381118
J2: QUADRANT; Hirose_FH12-16S-0.5SH_1x16-1MP_P0.50mm_Horizontal; MPN FH12-16S-0.5SH(55); LCSC C2837584
J3: POWER; PinHeader_1x08_P2.54mm_Vertical
J4: ANALOG; PinHeader_1x06_P2.54mm_Vertical
J5: DIGITAL 0-7; PinHeader_1x08_P2.54mm_Vertical
J6: DIGITAL 8-15; PinHeader_1x10_P2.54mm_Vertical
JP1: 5VA: 1 LDO / 3 BUCK; PinHeader_1x03_P2.54mm_Vertical
L1: 2u2; L_Bourns_SRN6045TA; MPN SRN6045TA-2R2M; LCSC C167219
R1, R2, R4: 100k; R_0603_1608Metric
R3: 523k; R_0603_1608Metric
R5: 470R; R_0603_1608Metric
R6: 49R9; R_0603_1608Metric
TP1: LED_END; TestPoint_Pad_1.5x1.5mm
TP2: 5VA; TestPoint_Pad_1.5x1.5mm
TP3: 5V; TestPoint_Pad_1.5x1.5mm
TP4: 3V3; TestPoint_Pad_1.5x1.5mm
TP5: GND; TestPoint_Pad_1.5x1.5mm
TP6: VIN; TestPoint_Pad_1.5x1.5mm
TP7: ADC1; TestPoint_Pad_1.5x1.5mm
U1: TPS62130; QFN-16-1EP_3x3mm_P0.5mm_EP1.75x1.75mm; MPN TPS62130RGTR; LCSC C74016
U2: LP2985-5.0; SOT-23-5; MPN LP2985AIM5-5.0; LCSC C129541
U3: 74AHCT1G125; SOT-23-5; MPN SN74AHCT1G125DBVR; LCSC C350557

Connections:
3V3: C14.1, J2.5, J3.4, TP4.1
5V: C5.1, C6.1, C12.1, F2.1, JP1.3, L1.2, R2.2, R3.1, TP3.1, U1.8 (DEF), U1.14 (VOS), U3.5 (VCC)
5VA: C10.1, C11.1, FB1.2, J2.2, TP2.1
5VA_LDO: C9.1, JP1.1, U2.5 (VOUT)
5VA_RAW: FB1.1, JP1.2
5V_LED: C7.1, F2.2, J2.10
ADC1: C13.1, J4.1, R6.2, TP7.1
AMP_OUT1: J2.4, R6.1
BUCK_EN: R1.1, U1.13 (EN)
BUCK_FB: R3.2, R4.1, U1.5 (FB)
BUCK_PG: R2.1, U1.4 (PG)
BUCK_SS: C4.1, U1.9 (SS/TR)
DAMP_EN_N: J2.15, J5.7
GND: C1.2, C2.2, C3.2, C4.2, C5.2, C6.2, C7.2, C8.2, C9.2, C10.2, C11.2, C12.2, C13.2, C14.2, D2.1 (A1), J1.2, J1.3, J2.1, J2.3, J3.6, J3.7, J6.7, R4.2, TP5.1, U1.6 (GND), U1.7 (FSW), U1.15 (GND), U1.16 (GND), U1.17 (GND), U2.2 (GND), U3.1, U3.3 (GND)
LDO_BP: C8.1, U2.4 (BP)
LED_DIN1: J2.7, R5.2
LED_DINB: R5.1, U3.4
LED_DIN_MCU: J6.6, U3.2
LED_END: J2.13, TP1.1
MUX_A0: J2.6, J5.4
MUX_A1: J2.8, J5.5
MUX_A2: J2.9, J5.6
MUX_EN_H: J2.12, J4.5
MUX_EN_L: J2.11, J4.6
PULSE_EN: J2.14, J4.3
SW: L1.1, U1.1 (SW), U1.2 (SW), U1.3 (SW)
VIN: C1.1, C2.1, C3.1, F1.2, J2.16, R1.2, TP6.1, U1.10 (VIN), U1.11 (VIN), U1.12 (VIN), U2.1 (VIN), U2.3 (ON/~OFF)
VIN_JACK: D1.2 (A), J1.1
VIN_RAW: D1.1 (K), D2.2 (A2), F1.1

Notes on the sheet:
12 V INPUT
5 V BUCK, LED RAIL
5VA ANALOG ISLAND
QUADRANT LINK
NUCLEO
TEST POINTS


Board: 2 copper layers, 80.0 x 56.0 mm, 43 parts (0 on the bottom side), 29 nets.

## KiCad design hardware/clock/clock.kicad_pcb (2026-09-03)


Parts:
BT1: 18650; BatteryHolder_Keystone_1042_1x18650
BZ1: 12 mm; Buzzer_12x9.5RM7.6
C1, C2: 4u7; C_0603_1608Metric
C3, C6: 1u; C_0603_1608Metric
C4: 10u; C_0603_1608Metric
C5, C7: 100n; C_0603_1608Metric
C8: 22u; C_0603_1608Metric
D1: CHG; LED_0603_1608Metric
D2: BAV99; SOT-23; MPN BAV99; LCSC C2500
H1, H2, H3, H4: M3; MountingHole_3.2mm_M3_Pad
J1: USB-C; USB_C_Receptacle_GCT_USB4085; MPN USB4085-GF-A; LCSC C2988369
J2: POWER SWITCH; PinHeader_1x02_P2.54mm_Vertical
J3: PROG; PinHeader_1x06_P2.54mm_Vertical
J4: TFT 2.4; PinHeader_1x14_P2.54mm_Vertical
Q1: AO3400A; SOT-23; MPN AO3400A; LCSC C20917
Q2: AO3401A; SOT-23; MPN AO3401A; LCSC C15127
R1, R2: 5k1; R_0603_1608Metric
R3: 2k; R_0603_1608Metric
R4: 1k; R_0603_1608Metric
R5, R6, R14, R16, R17: 100k; R_0603_1608Metric
R7, R8, R9, R10, R11, R12, R13: 10k; R_0603_1608Metric
R15: 56k; R_0603_1608Metric
SW1: BOOT; SW_SPST_PTS645; MPN PTS645SM43SMTR92; LCSC C221929
SW2: EN; SW_SPST_PTS645; MPN PTS645SM43SMTR92; LCSC C221929
SW3: WHITE; SW_PUSH_6mm_H4.3mm; MPN TS-1187A
SW4: BLACK; SW_PUSH_6mm_H4.3mm; MPN TS-1187A
SW5: EC11; RotaryEncoder_Alps_EC11E-Switch_Vertical_H20mm; MPN EC11E15244B2
TP1: 3V3; TestPoint_Pad_1.5x1.5mm
TP2: GND; TestPoint_Pad_1.5x1.5mm
TP3: VSW; TestPoint_Pad_1.5x1.5mm
U1: ESP32-S3-WROOM-1; MPN ESP32-S3-WROOM-1-N8; LCSC C2913204
U2: MCP73831; DFN-8-1EP_2x3mm_P0.5mm_EP0.61x2.2mm; MPN MCP73831T-2ACI/MC; LCSC C424093
U3: AP2112K-3.3; SOT-23-5; MPN AP2112K-3.3TRG1; LCSC C51118

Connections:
3V3: C4.1, C7.1, C8.1, J3.1, J4.1, Q2.2 (S), R7.2, R8.2, R9.2, R10.2, R11.2, R12.2, R13.2, R17.2, TP1.1, U1.2 (3V3), U3.5 (VOUT)
BUZZER: Q1.1 (G), R14.1, U1.22 (IO14)
BUZ_DRV: BZ1.2 (-), D2.3 (K), Q1.3 (D)
CC1: J1.A5 (CC1), R1.1
CC2: J1.B5 (CC2), R2.1
CHG_SENSE: R15.2, R16.1, U1.38 (IO2)
CHG_STAT: R4.2, R15.1, U2.5 (STAT)
ENC_A: R11.1, SW5.A, U1.17 (IO9)
ENC_B: R12.1, SW5.B, U1.18 (IO10)
ENC_SW: R13.1, SW5.S1, U1.19 (IO11)
ESP_EN: C6.1, J3.3, R7.1, SW2.1, U1.3 (EN)
ESP_IO0: J3.4, R8.1, SW1.1, U1.27 (IO0)
ESP_RXD: J3.6, U1.36 (RXD0)
ESP_TXD: J3.5, U1.37 (TXD0)
GND: BT1.2 (-), C1.2, C2.2, C3.2, C4.2, C5.2, C6.2, C7.2, C8.2, D2.1 (K), H1.1, H2.1, H3.1, H4.1, J1.A1 (GND), J1.A12 (GND), J1.B1 (GND), J1.B12 (GND), J1.S1 (SHIELD), J3.2, J4.2, Q1.2 (S), R1.2, R2.2, R3.2, R6.2, R14.2, R16.2, SW1.2, SW2.2, SW3.2, SW4.2, SW5.C, SW5.S2, TP2.1, U1.1 (GND), U1.40 (GND), U1.41 (GND), U2.6 (V_{SS}), U3.2 (GND)
LED_CHG_K: D1.1 (K), R4.1
PROG: R3.1, U2.8 (PROG)
SPI_MISO: J4.9, J4.13, U1.10 (IO17)
SPI_MOSI: J4.6, J4.12, U1.9 (IO16)
SPI_SCK: J4.7, J4.10, U1.8 (IO15)
SW_BLACK: R10.1, SW4.1, U1.21 (IO13)
SW_WHITE: R9.1, SW3.1, U1.20 (IO12)
TFT_CS: J4.3, U1.4 (IO4)
TFT_DC: J4.5, U1.5 (IO5)
TFT_LED: J4.8, Q2.3 (D)
TFT_LED_N: Q2.1 (G), R17.1, U1.7 (IO7)
TFT_RST: J4.4, U1.6 (IO6)
T_CS: J4.11, U1.12 (IO8)
T_IRQ: J4.14, U1.11 (IO18)
VBAT_SENSE: C5.1, R5.2, R6.1, U1.39 (IO1)
VBUS: C1.1, D1.2 (A), J1.A4 (VBUS), J1.A9 (VBUS), J1.B4 (VBUS), J1.B9 (VBUS), U2.1 (V_{DD}), U2.2 (V_{DD})
VCELL: BT1.1 (+), C2.1, J2.1, U2.3 (V_{BAT}), U2.4 (V_{BAT})
VSW: BZ1.1 (+), C3.1, D2.2 (A), J2.2, R5.1, TP3.1, U3.1 (VIN), U3.3 (EN)

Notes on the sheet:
POWER
ESP32-S3
DISPLAY AND INPUTS
TEST AND MECHANICAL


Board: 2 copper layers, 110.0 x 60.0 mm, 50 parts (0 on the bottom side), 33 nets.

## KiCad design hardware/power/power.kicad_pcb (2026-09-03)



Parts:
C1, C2: 10u/50V; C_1206_3216Metric
C3, C4, C5, C14, C15, C16, C17: 1u; C_0603_1608Metric
C6, C7, C8, C11, C12, C13, C18, C19: 100n; C_0603_1608Metric
C9, C10: 10u/25V; C_1206_3216Metric
D1: SMBJ24A; D_SMB; MPN SMBJ24A; LCSC C113966
F1: 2A; Fuse_1206_3216Metric
H1, H2, H3, H4: M3; MountingHole_3.2mm_M3_Pad
J1: PD 20V IN; JST_XH_B2B-XH-A_1x02_P2.50mm_Vertical
J2: POWER SWITCH; JST_XH_B2B-XH-A_1x02_P2.50mm_Vertical
J3: BRAIN; PinHeader_2x04_P2.54mm_Vertical
J4: CELLS; JST_XH_B4B-XH-A_1x04_P2.50mm_Vertical
L1: 10u; L_Bourns_SRN6045TA; MPN SRN6045TA-100M; LCSC C167222
Q1, Q2: AO3401A; SOT-23; MPN AO3401A; LCSC C15127
Q3, Q4, Q5, Q6: AO3400A; SOT-23; MPN AO3400A; LCSC C20917
R1, R35: 10m; R_1206_3216Metric
R2: 10R; R_0603_1608Metric
R3, R4, R5, R6, R26, R34: 10k; R_0603_1608Metric
R7: 5k23; R_0603_1608Metric
R8, R10, R12, R14, R38: 100k; R_0603_1608Metric
R9: 43k2; R_0603_1608Metric
R11: 3k16; R_0603_1608Metric
R13: 17k8; R_0603_1608Metric
R15: 20k; R_0603_1608Metric
R17: 50m; R_1206_3216Metric
R18: 0R; R_0603_1608Metric
R21, R22, R23, R24, R28, R29, R30, R31: 1k; R_0603_1608Metric
R25: 100R; R_0603_1608Metric
R27: 5m; R_1206_3216Metric
R32, R33: 1M; R_0603_1608Metric
R36, R37: 4k7; R_0603_1608Metric
R39: 30k1; R_0603_1608Metric
RT1, RT2: 10k NTC; R_0603_1608Metric; MPN NCP18XH103F03RB
SW1: WAKE; SW_SPST_PTS645; MPN PTS645SM43SMTR92; LCSC C221929
TP1: PACK+; TestPoint_Pad_1.5x1.5mm
TP2: GND; TestPoint_Pad_1.5x1.5mm
TP3: BAT-; TestPoint_Pad_1.5x1.5mm
TP4: 3V3_BMS; TestPoint_Pad_1.5x1.5mm
U1: BQ24610; QFN-24-1EP_4x4mm_P0.5mm_EP2.7x2.7mm; MPN BQ24610RGER; LCSC C130050
U2: BQ76920; TSSOP-20_4.4x6.5mm_P0.65mm; MPN BQ76920PWR; LCSC C130052
U3: INA219; SOIC-8_3.9x4.9mm_P1.27mm; MPN INA219BIDR; LCSC C138092

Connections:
3V3_BMS: C17.1, C19.1, R4.2, R5.2, R6.2, R26.2, R34.2, R36.2, R37.2, R38.2, TP4.1, U2.8 (REGOUT), U3.5 (VS)
ACDRV: Q1.1 (G), Q2.1 (G), U1.3 (~ACDRV)
ACMID: Q1.3 (D), Q2.3 (D)
ACN: Q1.2 (S), R1.2, U1.1 (ACN)
ACSET: R12.2, R13.1, U1.16 (ACSET)
AFE_SRN: C18.2, R29.2, U2.19 (SRN)
AFE_SRP: C18.1, R28.2, U2.18 (SRP)
ALERT: R34.1, U2.20 (ALERT)
BAT-: C11.2, C14.2, C15.2, C16.2, C17.2, C19.2, J4.1, R27.1, R28.1, RT2.2, TP3.1, U2.3 (VSS), U2.17 (VC0), U3.1 (A1), U3.2 (A0), U3.6 (GND)
BAT_F: C14.1, R24.2, U2.10 (BAT)
BTST: C6.1, U1.22 (BTST)
CAP1: C16.1, U2.7 (CAP1)
CELL1: J4.2, R21.1
CELL1_F: C11.1, C12.2, R21.2, U2.16 (VC1)
CELL2: J4.3, R22.1
CELL2_F: C12.1, C13.2, R22.2, U2.15 (VC2)
CELL3: J4.4, R23.1, R24.1, R25.1, R35.1, U3.8 (IN+)
CELL3_F: C13.1, R23.2, U2.12 (VC5), U2.13 (VC4), U2.14 (VC3)
CHG: R31.1, U2.2 (CHG)
CHG_CE: R3.1, U1.4 (CE)
CHG_G: Q6.1 (G), R31.2, R33.1
CHG_PG: R6.1, U1.8 (~PG)
CHG_STAT: J3.7, R4.1, U1.5 (STAT1)
CHG_STAT2: R5.1, U1.9 (STAT2)
DSG: R30.1, U2.1 (DSG)
DSG_G: Q5.1 (G), R30.2, R32.1
DSG_MID: Q5.3 (D), Q6.3 (D)
GND: C1.2, C2.2, C3.2, C4.2, C5.2, C7.2, C8.2, C9.2, C10.2, D1.1 (A1), H1.1, H2.1, H3.1, H4.1, J1.2, J3.3, J3.4, Q4.2 (S), Q6.2 (S), R9.2, R11.2, R13.2, R15.2, R33.2, R39.2, RT1.2, SW1.2, TP2.1, U1.17 (GND), U1.25 (GND)
HIDRV: Q3.1 (G), U1.21 (HIDRV)
ISET1: R8.2, R9.1, U1.11 (ISET1)
ISET2: R10.2, R11.1, U1.15 (ISET2)
LODRV: Q4.1 (G), U1.19 (LODRV)
PACK+: F1.1, R14.1, R18.2, R35.2, TP1.1, U3.7 (IN-)
PACK-PRE: Q5.2 (S), R27.2, R29.1, R32.2
PH: C6.2, L1.1, Q3.2 (S), Q4.3 (D), U1.20 (PH)
PWR_KEY: J3.8, R38.1, SW1.1
REGN: C4.1, R3.2, U1.18 (REGN)
REGSRC: C15.1, R25.2, U2.9 (REGSRC)
SCL: J3.5, R37.1, U2.5 (SCL), U3.4 (SCL)
SDA: J3.6, R36.1, U2.4 (SDA), U3.3 (SDA)
SRN: C10.1, R17.2, R18.1, U1.13 (SRN)
SRP: C9.1, L1.2, R17.1, U1.14 (SRP)
TS: R7.2, R39.1, RT1.1, U1.6 (TS)
TS1: R26.1, RT2.1, U2.6 (TS1)
TTC: C7.1, U1.7 (TTC)
VAD: C1.1, D1.2 (A2), J1.1, R1.1, R2.1, U1.2 (ACP)
VBAT_OUT: F1.2, J2.1
VBAT_SW: J2.2, J3.1, J3.2
VCC: C3.1, R2.2, U1.24 (VCC)
VCHG_IN: C2.1, Q2.2 (S), Q3.3 (D)
VFB: C8.1, R14.2, R15.1, U1.12 (VFB)
VREF: C5.1, R7.1, R8.1, R10.1, R12.1, U1.10 (VREF)

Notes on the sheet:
INPUT AND CHARGER
PROTECTION AFE
GAUGE, SWITCH, LINKS


Board: 2 copper layers, 100.0 x 60.0 mm, 82 parts (0 on the bottom side), 52 nets.

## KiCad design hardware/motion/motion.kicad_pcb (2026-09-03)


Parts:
C1, C2: 100u/25V; CP_Elec_8x10.5
C3, C4, C5: 100n; C_0603_1608Metric
C6: 47u/10V; CP_Elec_6.3x7.7
H1, H2, H3, H4: M3; MountingHole_3.2mm_M3_Pad
J1A: STEPSTICK 1 LOGIC; PinHeader_1x08_P2.54mm_Vertical
J1B: STEPSTICK 1 POWER; PinHeader_1x08_P2.54mm_Vertical
J2A: STEPSTICK 2 LOGIC; PinHeader_1x08_P2.54mm_Vertical
J2B: STEPSTICK 2 POWER; PinHeader_1x08_P2.54mm_Vertical
J3: MOTOR 1; JST_XH_B4B-XH-A_1x04_P2.50mm_Vertical
J4: MOTOR 2; JST_XH_B4B-XH-A_1x04_P2.50mm_Vertical
J5: ENDSTOP X; JST_XH_B3B-XH-A_1x03_P2.50mm_Vertical
J6: ENDSTOP Y; JST_XH_B3B-XH-A_1x03_P2.50mm_Vertical
J7: SERVO; JST_XH_B3B-XH-A_1x03_P2.50mm_Vertical
J8: BRAIN; PinHeader_2x10_P2.54mm_Vertical
R1, R2: 1k; R_0603_1608Metric
R3, R4, R5, R6: 0R; R_0603_1608Metric
R7, R8: 10k; R_0603_1608Metric
TP1: VBAT; TestPoint_Pad_1.5x1.5mm
TP2: GND; TestPoint_Pad_1.5x1.5mm
TP3: TMC_RX; TestPoint_Pad_1.5x1.5mm

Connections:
3V3: C5.1, J1B.7, J2A.2, J2B.7, J5.2, J6.2, J8.16, R7.2, R8.2
5V: C6.1, J7.2, J8.15
DIR1: J1A.8, J8.6
DIR2: J2A.8, J8.8
ENDSTOP_X: J5.3, J8.12
ENDSTOP_Y: J6.3, J8.13
GND: C1.2, C2.2, C3.2, C4.2, C5.2, C6.2, H1.1, H2.1, H3.1, H4.1, J1A.2, J1A.3, J1A.6, J1B.2, J1B.8, J2A.3, J2A.6, J2B.2, J2B.8, J5.1, J6.1, J7.3, J8.3, J8.4, J8.17, J8.18, TP2.1
M1_1A: J1B.5, J3.1
M1_1B: J1B.6, J3.2
M1_2A: J1B.4, J3.3
M1_2B: J1B.3, J3.4
M2_1A: J2B.5, J4.1
M2_1B: J2B.6, J4.2
M2_2A: J2B.4, J4.3
M2_2B: J2B.3, J4.4
MOT_ALARM: J8.19, R7.1
MOT_DIAG: J8.20, R8.1
MOT_EN: J1A.1, J2A.1, J8.9
SERVO: J7.1, J8.14
STEP1: J1A.7, J8.5
STEP2: J2A.7, J8.7
TMC_RX: J8.11, R5.2, R6.2, TP3.1
TMC_RX_1: R3.2, R5.1
TMC_RX_2: R4.2, R6.1
TMC_TX: J8.10, R1.1, R2.1
UART1: J1A.4, J1A.5, R1.2, R3.1
UART2: J2A.4, J2A.5, R2.2, R4.1
VBAT: C1.1, C2.1, C3.1, C4.1, J1B.1, J2B.1, J8.1, J8.2, TP1.1

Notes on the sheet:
STEPSTICKS
MOTORS, ENDSTOPS, SERVO
BRAIN LINK


Board: 2 copper layers, 90.0 x 60.0 mm, 31 parts (0 on the bottom side), 28 nets.

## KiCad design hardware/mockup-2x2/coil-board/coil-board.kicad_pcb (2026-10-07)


Board: 4 copper layers, 100.0 x 100.0 mm, 9 parts (0 on the bottom side), 5 nets.

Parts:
H1, H2, H3, H4: NPTH; NPTH_3.2
J1: COIL_JOINT_1x12
M1, M2, M3, M4: NPTH; NPTH_3.2

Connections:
C1: J1.2, J1.3
C2: J1.8, J1.9
C3: J1.4, J1.5
C4: J1.6, J1.7
GND: J1.1, J1.10

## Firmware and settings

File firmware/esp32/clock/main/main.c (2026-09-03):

/* Rocker chess clock: two microswitches under the bar, an encoder for
 * the menus, a buzzer, a 2.4 inch SPI display and a BLE link to the
 * board's bridge (Nordic UART Service, central role). Pins follow
 * tools/boardgen/clock.py (ESP_PINS). Not compiled in CI, see
 * ../README.md. */
#include <stdio.h>
#include <string.h>

#include "chessclock.h"
#include "driver/gpio.h"
#include "driver/ledc.h"
#include "esp_log.h"
#include "esp_timer.h"
#include "freertos/FreeRTOS.h"
#include "freertos/queue.h"
#include "freertos/task.h"
#include "nus.h"
#include "proto.h"
#include "ui.h"

#define PIN_SW_WHITE 12
#define PIN_SW_BLACK 13
#define PIN_ENC_A 9
#define PIN_ENC_B 10
#define PIN_ENC_SW 11
#define PIN_BUZZER 14

static const char *TAG = "clock";

typedef enum { EV_WHITE, EV_BLACK, EV_ENC_CW, EV_ENC_CCW, EV_ENC_PUSH } event_t;

static QueueHandle_t events;
static chessclock_t clk;
static proto_reader_t from_board;

/* presets shown in the menu: base seconds, increment seconds, mode */
static const struct { uint32_t base_s, inc_s; clock_mode_t mode; const char *label; } PRESETS[] = {
    {180, 2, MODE_FISCHER, "3+2"},   {300, 0, MODE_SIMPLE, "5+0"},
    {600, 0, MODE_SIMPLE, "10+0"},   {900, 10, MODE_FISCHER, "15+10"},
    {1800, 0, MODE_SIMPLE, "30+0"},  {5400, 30, MODE_FISCHER, "90+30"},
    {0, 0, MODE_FREE, "libre"},
};
static int preset = 3;

static uint32_t now_ms(void) { return (uint32_t)(esp_timer_get_time() / 1000); }

/* ------------------------------------------------------------- inputs */

static void IRAM_ATTR on_gpio(void *arg) {
    event_t ev = (event_t)(intptr_t)arg;
    BaseType_t woken = pdFALSE;
    xQueueSendFromISR(events, &ev, &woken);
    if (woken) {
        portYIELD_FROM_ISR();
    }
}

static void IRAM_ATTR on_encoder(void *arg) {
    (void)arg;
    /* half-step decoding on the A edge: direction from B */
    event_t ev = gpio_get_level(PIN_ENC_B) ? EV_ENC_CW : EV_ENC_CCW;
    BaseType_t woken = pdFALSE;
    xQueueSendFromISR(events, &ev, &woken);
    if (woken) {
        portYIELD_FROM_ISR();
    }
}

static void inputs_init(void) {
    gpio_config_t in = {
        .pin_bit_mask = (1ull << PIN_SW_WHITE) | (1ull << PIN_SW_BLACK) | (1ull << PIN_ENC_A) |
                        (1ull << PIN_ENC_B) | (1ull << PIN_ENC_SW),
        .mode = GPIO_MODE_INPUT,
        .pull_up_en = GPIO_PULLUP_ENABLE,
        .intr_type = GPIO_INTR_NEGEDGE,
    };
    gpio_config(&in);
    gpio_set_intr_type(PIN_ENC_B, GPIO_INTR_DISABLE);
    gpio_install_isr_service(0);
    gpio_isr_handler_add(PIN_SW_WHITE, on_gpio, (void *)EV_WHITE);
    gpio_isr_handler_add(PIN_SW_BLACK, on_gpio, (void *)EV_BLACK);
    gpio_isr_handler_add(PIN_ENC_SW, on_gpio, (void *)EV_ENC_PUSH);
    gpio_isr_handler_add(PIN_ENC_A, on_encoder, NULL);
}

/* ------------------------------------------------------------- buzzer */

static void buzzer_init(void) {
    ledc_timer_config_t t = {
        .speed_mode = LEDC_LOW_SPEED_MODE, .duty_resolution = LEDC_TIMER_10_BIT,
        .timer_num = LEDC_TIMER_0, .freq_hz = 2700, .clk_cfg = LEDC_AUTO_CLK,
    };
    ledc_timer_config(&t);
    ledc_channel_config_t ch = {
        .gpio_num = PIN_BUZZER, .speed_mode = LEDC_LOW_SPEED_MODE, .channel = LEDC_CHANNEL_0,
        .timer_sel = LEDC_TIMER_0, .duty = 0, .hpoint = 0,
    };
    ledc_channel_config(&ch);
}

static void beep(int times) {
    for (int i = 0; i < times; i++) {
        ledc_set_duty(LEDC_LOW_SPEED_MODE, LEDC_CHANNEL_0, 512);
        ledc_update_duty(LEDC_LOW_SPEED_MODE, LEDC_CHANNEL_0);
        vTaskDelay(pdMS_TO_TICKS(120));
        ledc_set_duty(LEDC_LOW_SPEED_MODE, LEDC_CHANNEL_0, 0);
        ledc_update_duty(LEDC_LOW_SPEED_MODE, LEDC_CHANNEL_0);
        vTaskDelay(pdMS_TO_TICKS(80));
    }
}

/* --------------------------------------------------------------- link */

static void send_times(void) {
    char line[48];
    snprintf(line, sizeof line, "C,%ld,%ld,%c\n", (long)clk.left_ms[0], (long)clk.left_ms[1],
             clk.to_move == SIDE_WHITE ? 'w' : 'b');
    nus_central_send(line);
}

static void send_new_game(void) {
    char line[48];
    snprintf(line, sizeof line, "N,%s,%lu,%lu\n", clock_mode_name(clk.mode),
             (unsigned long)(clk.base_ms / 1000u), (unsigned long)(clk.increment_ms / 1000u));
    nus_central_send(line);
}

static void on_board_line(const char *line, void *ctx) {
    (void)ctx;
    proto_msg_t m;
    if (!proto_parse(line, &m)) {
        return;
    }
    switch (m.type) {
    case 'S':                          /* game state from the board */
        if (m.n >= 1) {
            ui_set_status(m.field[0]);
        }
        break;
    case 'M':                          /* a move was detected: show it */
        if (m.n >= 1) {
            ui_set_last_move(m.field[0]);
        }
        break;
    case 'P':
        if (m.n >= 3) {
            ui_set_board_battery(m.field[2]);
        }
        break;
    default:
        break;
    }
}

static void on_ble_rx(const uint8_t *data, size_t n, void *ctx) {
    proto_reader_feed(&from_board, data, n, on_board_line, ctx);
}

/* --------------------------------------------------------------- main */

static void apply_preset(void) {
    clock_init(&clk, PRESETS[preset].mode, PRESETS[preset].base_s, PRESETS[preset].inc_s);
    ui_set_preset(PRESETS[preset].label);
    send_new_game();
}

void app_main(void) {
    events = xQueueCreate(16, sizeof(event_t));
    inputs_init();
    buzzer_init();
    ui_init();
    nus_central_start(on_ble_rx, NULL);
    apply_preset();

    uint32_t last = now_ms(), last_sent = last;
    bool in_menu = false;
    for (;;) {
        event_t ev;
        while (xQueueReceive(events, &ev, 0)) {
            uint32_t t = now_ms();
            switch (ev) {
            case EV_WHITE:
            case EV_BLACK: {
                side_t s = ev == EV_WHITE ? SIDE_WHITE : SIDE_BLACK;
                clock_state_t before = clk.state;
                clock_press(&clk, s, t);
                if (clk.state != before || clk.to_move != s) {
                    char line[8];
                    snprintf(line, sizeof line, "T,%c\n", s == SIDE_WHITE ? 'w' : 'b');
                    nus_central_send(line);
                    send_times();
                }
                break;
            }
            case EV_ENC_PUSH:
                if (clk.state == CLK_IDLE || clk.state == CLK_FLAG) {
                    in_menu = !in_menu;
                    if (!in_menu) {
                        apply_preset();
                    }
                } else {
                    clock_pause_toggle(&clk, t);
                }
                break;
            case EV_ENC_CW:
            case EV_ENC_CCW:
                if (in_menu) {
                    int n = (int)(sizeof PRESETS / sizeof PRESETS[0]);
                    preset = (preset + (ev == EV_ENC_CW ? 1 : n - 1)) % n;
                    ui_set_preset(PRESETS[preset].label);
                }
                break;
            }
        }
        uint32_t t = now_ms();
        if (clock_tick(&clk, t - last, t)) {
            beep(clk.state == CLK_FLAG ? 3 : 1);
            if (clk.state == CLK_FLAG) {
                char line[16];
                snprintf(line, sizeof line, "R,%c,flag\n", clk.flagged == SIDE_WHITE ? 'w' : 'b');
                nus_central_send(line);
            }
        }
        last = t;
        if (t - last_sent >= 1000 && clk.state == CLK_RUNNING) {
            send_times();
            last_sent = t;
        }
        ui_render(&clk, in_menu, nus_central_connected());
        vTaskDelay(pdMS_TO_TICKS(50));
    }
    (void)TAG;
}

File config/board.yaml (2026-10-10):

# Single source of truth for every project constant.
#
# Only independent parameters live here. Derived quantities (resonant
# frequencies, mm diameters, gantry travels, total gap, autonomy) are
# computed by chessboard_calc and pinned by unit tests against the
# specification. No value is duplicated between this file and the code.
schema_version: 1

pitch:
  candidates_mm: [40, 50]      # both still computed and reported for comparison
  mockup_mm: 50                # fixed by the 100x100 mm PCB price tier
  plateau_mm: 50               # decided for the 8x8 board (ADR 0010): signal and Q

pieces:
  classes:                     # base_ratio: base diameter as a fraction of p
    pawn:   { base_ratio: 0.35, cap_nF: { white: 3.9, black: 12.0 } }
    knight: { base_ratio: 0.40, cap_nF: { white: 3.3, black: 10.0 } }
    bishop: { base_ratio: 0.40, cap_nF: { white: 2.7, black: 8.2 } }
    rook:   { base_ratio: 0.45, cap_nF: { white: 2.2, black: 6.8 } }
    queen:  { base_ratio: 0.45, cap_nF: { white: 1.8, black: 5.6 } }
    king:   { base_ratio: 0.45, cap_nF: { white: 1.5, black: 4.7 } }
  spare_queens_per_side: 1     # promotion hardware (critical review, F)
  mass_g: [20, 40]

corridor:
  tolerance_budget_mm: 0.8     # gantry +-0.5 plus base eccentricity +-0.3

resonator:
  L_target_uH: 45.0
  L_tol_pct: 5.0               # hand-wound spread
  C_tol_pct: 1.0               # C0G 1 %
  q_nominal: 50
  q_min_with_magnet: 30        # acceptance floor of measurement 2
  # Acceptance for check_separation. Exact computation puts the worst
  # adjacent pair (3.3 / 3.9 nF, an E12 ratio-1.18 step) at 2.50 widths
  # for Q = 30, so the gate sits just below to catch real regressions
  # without tripping on the nominal design itself.
  min_separation_widths: 2.4
  # Worst-case frequency gap once both neighbors drift by the full
  # component tolerance; must stay well above the ~1 kHz measurement
  # resolution. Nominal design gives 7.1 kHz on the 12 / 10 nF pair.
  min_tolerance_gap_khz: 4.0
  coil:
    outer_margin_mm: 4.0       # d_out = base - 4
    inner_ratio: 0.40          # d_in = 0.40 * d_out, to confirm on mockup
    height_mm: 2.0
    wire_candidates_mm: [0.15, 0.20, 0.25, 0.315]
    insulation_extra_mm: 0.05  # enamel build on top of copper diameter
    fill_factor: 0.70          # round enameled wire, hand-wound
    proximity_factor: 2.5      # crude AC resistance multiplier, mockup calibrates

piece_magnet:
  material: "SrFe hard ferrite"
  br_T: 0.40
  outer_margin_mm: 5.0         # d = base - 5
  thickness_mm: 4.0

gap:                           # nominal total is derived: 1.6 + 2.0 + 3.0 + 0.5 = 7.1
  pcb_mm: 1.6
  air_mm: 2.0                  # clearance under the plywood: LED bodies and the
                               # quadrant front-end strip (ADR 0010, parts <= 1.8 mm)
  surface_mm: 3.0              # dry plywood (was acrylic); thickness is the
                               # only surface parameter that affects the signal
  felt_mm: 0.5
  max_total_mm: 8.0

sense_coil:
  outer_ratio: 0.80            # x p
  inner_ratio: 0.45            # x p
  layers: 4                    # all four layers in series
  L_target_uH: 18.0            # keeps SRF with ~40 pF mux 10x above band
  track_gap_mm: 0.15
  via_drill_mm: 0.30
  copper_um: 35                # 1 oz outer and inner copper
  # track width is derived: turns solved for L_target, spread over annulus

mux:
  part: ADG708
  ron_ohm: 4.0
  c_off_pF: 40.0
  idle_coil_policy: shorted    # both ends grounded (critical review, J)

measurement:
  band_hz: [200.0e+3, 650.0e+3]
  blanking_us: 2.0
  window_us: 128.0
  adc_sps: 4.0e+6
  fft_points: 512
  coherent_avg: 16
  idle_scan_hz: 5
  preamp_gain: [200, 500]
  bandpass_order: 4
  crosstalk_max_db: -20.0
  snr_min_db: 20.0
  preamp_noise_nv_rthz: 4.0    # input-referred amplifier noise density
  drive:                       # excitation model for signal estimates
    v: 12.0
    pulse_us: 1.0
    current_limit_a: 2.0
    excitation_efficiency: 0.5 # derates the ideal flux-transfer estimate

gantry:
  kinematics: corexy
  capture_band_ratio: 1.0      # width of each lateral capture band, x p
  y_margin_mm: 20.0            # travels derive: x = 10 p, y = 8 p + 20
  speed_mm_s: [60, 120]
  accel_mm_s2: [200, 500]
  settle_ms: 50
  driver: { part: TMC2209, mode: stealthchop, disable_at_idle: true }
  per_pitch:                   # discrete choices that do not scale continuously
    40: { motor: NEMA14, guide: "8 mm rods or MGN9" }
    50: { motor: NEMA17, guide: "MGN9 400 + 500" }
  homing: park_against_endstops  # re-zero at every park (critical review, H)

carriage:
  magnet: { material: "NdFeB N42", d_mm: 15.0, h_mm: 5.0 }
  engage_gap_mm: 6.0
  retract_gap_mm: 15.0
  actuator_candidates: [servo_permanent_magnet, electromagnet]  # open (brief 5.3)

friction:
  mu_felt_acrylic: 0.30
  lateral_fraction: [0.20, 0.30]
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

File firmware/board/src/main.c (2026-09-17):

/* Brain board firmware entry (ADR 0010): scans the four quadrants over
 * the shared coil bus, reports fa (FFT) on every coil and fb (comparator)
 * on quadrant 1, drives the 128 camp LEDs. Console on USART1, or on the
 * ST-Link virtual COM port when built with NUCLEO=1 (one reduced
 * quadrant of four coils on a Nucleo-G474RE, note 19). */

#include "app.h"

int main(void) {
    clock_init_170mhz();
    dwt_init();
    uart_init();
    adc_init();
    comp_init();
    fft_init();
    measure_init();
    led_init();

    uart_puts("# LC chessboard, " BOARD_NAME ", ");
    uart_put_uint(N_QUADRANTS);
    uart_puts(" quadrant(s) x ");
    uart_put_uint(COILS_PER_QUADRANT);
    uart_puts(" coils\n");
    uart_puts("# fs_hz=");
    uart_put_uint(adc_sample_rate_hz());
    uart_puts(" band=200k..650k, h for help\n");
    uart_puts("# csv: q,coil,sq,fa_hz,fb_hz,amp_mv,snr_db10\n");

    for (;;) {
        cli_poll();
    }
}

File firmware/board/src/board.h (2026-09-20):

/* Board-level constants and helpers for the brain board (STM32G474RE),
 * driving four 4x4 quadrants (ADR 0010). Built with NUCLEO=1 the same
 * firmware runs on a Nucleo-G474RE driving one reduced 2x2 quadrant
 * over the brain's bus pins: the bench of note 19. NUCLEO=1 NUCLEO_FULL=1
 * drives one full 4x4 quadrant plugged on that same bench shield. */

#ifndef BOARD_H
#define BOARD_H

#include <stdint.h>

#include "stm32g474xx.h"

#include "board_pins.h"

#ifndef NUCLEO
#define NUCLEO 0
#endif
#ifndef NUCLEO_FULL
#define NUCLEO_FULL 0
#endif

#define SYSCLK_HZ 170000000u

/* Analog chain constants (mirrors config/board.yaml). */
#define VREF_BIAS_V 1.65f
#define ADC_SAMPLES 512u
#define BAND_LO_HZ 200000u
#define BAND_HI_HZ 650000u
#define DRIVE_PULSE_NS 1000u
#define BLANKING_NS 2000u

/* Grid, LED chain and console of the two targets (values from board_pins.h). */
#if NUCLEO
#define N_QUADRANTS 1u
#if NUCLEO_FULL
/* one full 4x4 quadrant on the bench shield: same connector, same bus,
 * the coils 9..16 behind MUX_EN_H exactly as on the brain */
#define BOARD_NAME "nucleo bench, full quadrant"
#define COILS_PER_ROW QUADRANT_SQUARES
#define LED_N NUCLEO_FULL_LED_COUNT
#define LED_CHAIN NUCLEO_FULL_LED_CHAIN_SQ
#else
#define BOARD_NAME "nucleo bench"
#define COILS_PER_ROW REDUCED_SQUARES
#define LED_N NUCLEO_LED_COUNT
#define LED_CHAIN NUCLEO_LED_CHAIN_SQ
#endif
#define CONSOLE_TX_PORT NUCLEO_CONSOLE_TX_PORT
#define CONSOLE_TX_PIN NUCLEO_CONSOLE_TX_PIN
#define CONSOLE_RX_PORT NUCLEO_CONSOLE_RX_PORT
#define CONSOLE_RX_PIN NUCLEO_CONSOLE_RX_PIN
#if NUCLEO_CONSOLE_USART == 2u
#define CONSOLE_USART USART2
#define CONSOLE_CLK_ENABLE() (RCC->APB1ENR1 |= RCC_APB1ENR1_USART2EN)
#else
#error "bench.console.usart in config/board.yaml: only USART2 is wired here"
#endif
/* The bus rides the Arduino connectors of the Nucleo (bench.signals in the
 * yaml): the brain's own pins, except DAMP_EN_N which leaves PC2 (a Morpho
 * only pin) for D6 so the bench shield needs no Morpho socket. */
#undef ADC1_PORT
#undef ADC1_PIN
#define ADC1_PORT NUCLEO_ADC1_PORT
#define ADC1_PIN NUCLEO_ADC1_PIN
#undef PULSE_EN_PORT
#undef PULSE_EN_PIN
#define PULSE_EN_PORT NUCLEO_PULSE_EN_PORT
#define PULSE_EN_PIN NUCLEO_PULSE_EN_PIN
#undef MUX_A0_PORT
#undef MUX_A0_PIN
#define MUX_A0_PORT NUCLEO_MUX_A0_PORT
#define MUX_A0_PIN NUCLEO_MUX_A0_PIN
#undef MUX_A1_PORT
#undef MUX_A1_PIN
#define MUX_A1_PORT NUCLEO_MUX_A1_PORT
#define MUX_A1_PIN NUCLEO_MUX_A1_PIN
#undef MUX_A2_PORT
#undef MUX_A2_PIN
#define MUX_A2_PORT NUCLEO_MUX_A2_PORT
#define MUX_A2_PIN NUCLEO_MUX_A2_PIN
#undef MUX_EN_L_PORT
#undef MUX_EN_L_PIN
#define MUX_EN_L_PORT NUCLEO_MUX_EN_L_PORT
#define MUX_EN_L_PIN NUCLEO_MUX_EN_L_PIN
#undef MUX_EN_H_PORT
#undef MUX_EN_H_PIN
#define MUX_EN_H_PORT NUCLEO_MUX_EN_H_PORT
#define MUX_EN_H_PIN NUCLEO_MUX_EN_H_PIN
#undef DAMP_EN_N_PORT
#undef DAMP_EN_N_PIN
#define DAMP_EN_N_PORT NUCLEO_DAMP_EN_N_PORT
#define DAMP_EN_N_PIN NUCLEO_DAMP_EN_N_PIN
#undef LED_DIN_MCU_PORT
#undef LED_DIN_MCU_PIN
#define LED_DIN_MCU_PORT NUCLEO_LED_DIN_MCU_PORT
#define LED_DIN_MCU_PIN NUCLEO_LED_DIN_MCU_PIN
#else
#define BOARD_NAME "brain"
#define N_QUADRANTS PLATEAU_QUADRANTS
#define COILS_PER_ROW QUADRANT_SQUARES
#define LED_N LED_COUNT
#define LED_CHAIN LED_CHAIN_SQ
#define CONSOLE_TX_PORT MCU_TX_PORT
#define CONSOLE_TX_PIN MCU_TX_PIN
#define CONSOLE_RX_PORT MCU_RX_PORT
#define CONSOLE_RX_PIN MCU_RX_PIN
#define CONSOLE_USART USART1
#define CONSOLE_CLK_ENABLE() (RCC->APB2ENR |= RCC_APB2ENR_USART1EN)
#endif
#define COILS_PER_QUADRANT (COILS_PER_ROW * COILS_PER_ROW)
#define N_SQUARES (N_QUADRANTS * COILS_PER_QUADRANT)

static inline void gpio_set(GPIO_TypeDef *port, uint32_t pin) {
    port->BSRR = 1u << pin;
}

static inline void gpio_clear(GPIO_TypeDef *port, uint32_t pin) {
    port->BSRR = 1u << (pin + 16u);
}

static inline void gpio_write(GPIO_TypeDef *port, uint32_t pin, uint32_t level) {
    if (level) {
        gpio_set(port, pin);
    } else {
        gpio_clear(port, pin);
    }
}

static inline uint32_t gpio_read(GPIO_TypeDef *port, uint32_t pin) {
    return (port->IDR >> pin) & 1u;
}

static inline void gpio_out(GPIO_TypeDef *port, uint32_t pin) {
    port->MODER = (port->MODER & ~(3u << (2u * pin))) | (1u << (2u * pin));
}

static inline void gpio_in_pullup(GPIO_TypeDef *port, uint32_t pin) {
    port->MODER &= ~(3u << (2u * pin));
    port->PUPDR = (port->PUPDR & ~(3u << (2u * pin))) | (1u << (2u * pin));
}

static inline void gpio_analog(GPIO_TypeDef *port, uint32_t pin) {
    port->MODER |= 3u << (2u * pin);
}

static inline void gpio_af(GPIO_TypeDef *port, uint32_t pin, uint32_t af) {
    port->MODER = (port->MODER & ~(3u << (2u * pin))) | (2u << (2u * pin));
    volatile uint32_t *afr = &port->AFR[pin >> 3u];
    uint32_t shift = 4u * (pin & 7u);
    *afr = (*afr & ~(0xFu << shift)) | (af << shift);
}
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

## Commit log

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2026-08-29 Phase 0 : board.yaml, bibliotheque de calculs et garde-fous
    config/board.yaml est la source de verite unique : seuls les parametres
    independants y vivent, les grandeurs derivees (12 frequences, diametres,
    courses, entrefer, autonomie) sont calculees par chessboard_calc et
    epinglees par les tests contre la specification.
    Modules : inductance (Wheeler pancake et multicouche, Mohan, solveur
    inverse N(L), fenetre de bobinage, estimation de Q), resonance (plan de
    frequences, largeurs, separations a Q degrade et sous tolerances),
    corridor (contrainte de couloir sur les 21 paires de classes, garde-fou
    CI), coupling (mutuelle de Maxwell par decomposition en filaments,
    estimation du signal recu et d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
    [board.yaml]
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2026-08-29 Maquette : section mockup dans board.yaml et ADR 0008
    Deux cartes (bobines generee par script, analogique en shield Nucleo),
    mux differentiel ADG709 (corrige l'ADG708 8 vers 1 du brief, inapte au
    differentiel), excitation par FET dedie hors mux avec protection 330R
    et BAV99, chaine AD8421 G20 plus deux biquads MFB Butterworth G3,16.
    Modeles pydantic etendus, schema toujours strict.
    [board.yaml]
2026-08-29 Coilgen : generateur de spirales et carte bobines de la maquette
    Paquet coilgen : geometrie de spirales empilees en serie (arcs de
    liaison de 90 degres pour separer les vias de jonction des terminaux,
    sens de circulation identique sur les 4 couches, verifie par test),
    emetteur kicad_pcb minimal valide par kicad-cli, constructeur de la
    carte 100 x 100 (4 spirales, connecteur 1 x 10, trous de fixation et
    de support d'aimant), rendu matplotlib pour revue.
    8 tests de geometrie dont controle de clearance inter-nets par
    echantillonnage KDTree et test d'analyse par kicad-cli. Script
    d'export gerbers + percage, archive de fabrication commitee.
    [coil-board.kicad_pcb]
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2026-08-29 Protocole de mesure, module d'analyse et notebook
    Protocole des 8 mesures du brief plus les extensions de la lecture
    critique (M4bis entrefer max, M5bis detuning mutuel, M7bis effort de
    passage, M9 comparaison des voies A et B), avec criteres chiffres et
    gabarits CSV. Module d'analyse teste sur ringdowns synthetiques :
    extraction de Q par decrement logarithmique de l'enveloppe (2 % de
    justesse verifiee), largeur spectrale documentee comme borne
    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
    [m1_q_classe.csv, m2_q_ferrite_classe.csv, m4_snr.csv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]
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2026-08-29 Routeur : rails structurels, rasterisation conservative, correctifs
    Rastérisation des pads par intersection (les marques englobent le
    cuivre, les seuils de légalité n'ont plus besoin de marge d'erreur),
    neutralisation des cellules frontière partagées entre pads voisins de
    nets différents (source de chevauchements réels), rails VREF et 5VA
    pré-posés avec fenêtre de passage en face arrière, passe de nettoyage
    à garde de fabrication sur tout le trajet, pull-ups d'amortisseurs
    tirés au VIN local, chaîne resserrée autour du mux, plafond
    d'exploration A*.
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2026-08-29 Routeur : stubs de masse sans tolerance et traces manuels ancres
    Les stubs de masse exigent desormais la legalite pleine sur tout leur
    trajet (fin des empietements releves au localisateur pres du QFN), et
    les huit liaisons que le routeur ne fermait pas sont posees en routes
    structurelles ancrees sur les pads (BUCK_EN, VIN du LDO, M2_A, M4_B,
    epine LP_OUT, selection du mux depuis J4 avec contre-passes sous les
    deux rails).
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2026-08-29 Croisements de seeds corriges et passe de garantie DRC
    Echange des colonnes de descente des selections mux, descente M4_B a
    l'ouest du mux, garde seed contre seed au build. Passe finale de
    garantie : toute piste sous la garde de fabrication est retiree et sa
    liaison redevient un chevelu explicite a finir dans KiCad, la carte
    part donc DRC propre avec une liste de finition affichee.
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2026-08-30 Carte analogique generee : projet KiCad, gerbers, BOM JLC, rendu
    Artefacts complets de la carte analogique de la maquette : schema et
    PCB KiCad valides par kicad-cli, gerbers et percage archives, BOM et
    placements au format JLCPCB, netlist SPICE de la chaine, rendu PNG
    reference par le README. La carte part DRC zero avec plan de masse
    entier ; la liste de finition (une quinzaine de sauts locaux, coin
    buck surtout) est imprimee par le build et documentee dans le README
    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
    [analog-board.kicad_pcb, analog-board.kicad_sch, bom.csv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]
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2026-08-30 Carte analogique de reference : 18 restes contre 23, artefacts a jour
    Generation finale avec les trois seeds nord ouest : 464 pistes, 242
    vias, DRC zero, BUCK_SS, BUCK_DEF et la broche isolateur PI_3V3
    desormais fermes sans deplacement d'autres nets. Gerbers, placements
    JLC et rendu regeneres ; le README de la carte porte la liste de
    finition exacte (quatre liaisons jamais routees et les morceaux a
    raccorder) et la note de methode sur la saturation locale du routage.
    [analog-board.kicad_pcb, analog-board.kicad_sch]
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2026-08-30 Carte de reference avec passe de finition : 9 restes contre 18
    Regeneration des artefacts : 480 pistes, 249 vias, DRC zero, 9
    jonctions posees par la finition. VIN, SW, BUCK_PG, BUCK_SS,
    BUCK_DEF, 5VA et PI_3V3 sont desormais entiers ; restent cinq nets a
    fermer dans pcbnew (M1_A, C2_A, C3_B, BUCK_FB, VREF), leurs couloirs
    etant reellement occupes, verification geometrique a l'appui. README
    de la carte mis a jour, gerbers, placements JLC et rendu regeneres.
    [analog-board.kicad_pcb, analog-board.kicad_sch]
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2026-09-01 Carte bobines : 8 LED WS2812B chainees aux coins des cases
    Deux LED RGB adressables par case aux coins opposes (diagonale NE-SO
    pour la case 2, son coin NO tombant sous la rangee du connecteur),
    chacune avec 100 nF et sa paire de vias choisie par degagement.
    Distribution : donnees chainees sur In1 dans les couloirs, boucle 5V
    sur In2 (esquives des empilements de terminaux et de la rangee de
    pads), masse en face arriere (boucle, epine centrale, eperons choisis
    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
    [coil-board.kicad_pcb]
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2026-09-01 Reference LED complete : cartes, gabarit bois, protocole, docs
    Carte analogique regeneree avec le tampon deplace pres du connecteur
    MCU : les nets LED (donnees, tampon, 5V vers le joint 12 broches)
    sont entierement routes, 499 pistes, 259 vias, DRC zero, 12 jonctions
    de finition posees ; restent les sept couloirs satures connus de la
    bande des cellules et du coin buck, listes dans le README de la
    carte. Gabarit de percage surface-template (contour carte, visserie,
    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
    [analog-board.kicad_pcb, analog-board.kicad_sch, bom.csv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]
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2026-09-02 Série vidéo : bible, découpage en épisodes, tournage et montage
    Nouveau dossier docs/serie pour documenter la construction en épisodes
    courts verticaux tournés avec Romain et offerts avec le plateau.
    La bible fixe le concept (fil technique et fil du secret), le titre
    Échec et Watt, le format (9:16, 45 à 75 s, une idée par épisode), les
    rubriques récurrentes (le chiffre, la décision, le raté, le compte à
    rebours, le plateau de progression), la direction artistique (palette
    bois, cuivre, camp blanc, ambre, cyan de mesure ; grotesque pour les
    titres, mono pour les données), l'organisation à deux, la règle de
    publication en compte privé et le calendrier par saison.
    Le découp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
2026-09-02 Série vidéo : calendrier daté, rôles, publication en différé
    Deux dates fixées : anniversaire le 1er octobre 2026, remise du
    plateau à Noël. Un mois ne permet pas le plateau complet (cartes de
    la phase 2 non conçues, 2 à 5 semaines de commande) ; la bible
    l'explique et retient Noël pour la remise, le 1er octobre devenant
    une étape avec deux variantes (la promesse : une pièce équipée et la
    maquette qui joue sa note, épisode E13bis optionnel ; ou le silence).
    Rétro-planning semaine par semaine jusqu'au 25 décembre, avec la
    contrainte clé : concevoir le plateau 8 x 8 en septembre pendant
    l'attente des cartes de la maquette, commande des quadrants à la
    mi-octobre, aucune mar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
2026-09-02 Generateur de quadrant 4 x 4 : spirales, echappees, LED, distribution, bande de frontal
    tools/quadgen produit hardware/quadrant/quadrant.kicad_pcb depuis
    config/board.yaml (section plateau.quadrant) :
    - mise en page calculee pour une grille n x n (layout.py) : bornes de
    bobine alternees par rangee, bandes d'echappee a huit voies entre
    les paires de rangees, voies verticales et cellules du frontal en
    face de leur bande, LED aux memes coins sur toutes les cases,
    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
    [quadrant.kicad_pcb]
2026-09-03 Frontal du quadrant, cinq cartes generees, firmware cerveau et ESP32, protocole
    Quadrant : frontal complet (16 cellules, deux ADG1607, decodeurs
    74HC4514 et 74HC154, inverseur, chaine AD8421 et OPA2810, FPC 16
    broches) place et route par le routeur A* multicouche ; sorties des
    boitiers fins par eventail (troncon, via 0,45 mm sur deux rangees,
    couloir de sortie), bandes d'echappee, controle d'isolement exact a
    chaque route, zone du milieu en une colonne.
    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
    [bom.csv, brain.kicad_pcb, brain.kicad_sch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]
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2026-09-03 STL et STEP versionnes ; feuille de route en deux phases, chariot en phase 2 (note 07, ADR 0010, README)
    [horloge-barre.step, horloge-barre.stl, horloge-boitier.step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]
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2026-09-03 Revue des cartes (lot 1) : erreurs de câblage corrigées, DRC KiCad, note 14
    Générateurs : schéma sans chevauchement de groupes (le quadrant reliait
    GND à 5VA), cours d'empreinte lues au format KiCad 7, règles du projet
    égales au build (vias d'éventail), vias dédoublonnées et tenues hors des
    trous, contrôle d'isolement exact, net tie des bobines hors du trou de
    via, modules ESP32 au bord avec leur dégagement d'antenne.
    Cartes : FET d'entrée du BQ24610 en canal P, sources DSG et CHG du
    BQ76920, réseau TS et consignes de charge (50 mohms, 1 A), UART de
    l'ESP32 et SWD du cerveau, lecture de charge, rétroéclairage et USB de
    l'horloge, broches libres déclarées non connectées.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
2026-09-03 Bobines : vias d'empilement hors des spires ; puissance et horloge régénérées
    Les trois vias d'empilement de chaque bobine du quadrant tombaient dans
    les bandes de spires des deux autres couches et court-circuitaient la
    bobine ; elles sont décalées radialement hors des bandes, reliées par
    un tronçon radial, le net tie posé sur le tronçon de la dernière
    jonction dans le creux, et les contrôles maison n'exemptent plus que
    les deux pastilles du net tie.
    Carte puissance et horloge régénérées avec les générateurs corrigés
    (DRC KiCad réduit aux nets ouverts et à la sérigraphie), tableaux et
    notes mis à jour, rapports de DRC ignorés par git.
    [bom.csv, clock.kicad_pcb, clock.kicad_sch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]
2026-09-03 Quadrant régénéré avec les bobines corrigées ; pastilles libres bloquantes pour le routeur
    Le routeur du frontal ignorait les pastilles non connectées (NC des
    mux) et y faisait passer une piste de masse : toute pastille libre est
    désormais un obstacle dans le routeur et dans les contrôles. Quadrant
    régénéré avec les vias d'empilement décalées et le net tie dans le
    creux ; note 14 complétée.
    [quadrant.kicad_pcb, quadrant.kicad_sch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]
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2026-09-03 Cerveau : build final ; résultats du DRC à jour (aucune erreur hors nets ouverts)
    [brain.kicad_pcb, brain.kicad_sch]
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2026-09-13 Quadrant réduit 2 x 2 généré : projet KiCad à six feuilles, PCB routé, README, rendus
    hardware/quadrant-2x2 : feuille racine et feuilles rails, cells-1,
    select, chain, leds, PCB de 120 x 108 mm (quatre spirales, huit LED,
    frontal complet), BOM, placements, banc SPICE. Build : aucune route
    LED ou alimentation ouverte, aucun défaut d'isolement, deux nets du
    frontal à finir dans pcbnew (INA_INM, GND) ; DRC KiCad sans erreur hors
    éléments non connectés. Lignes de masse LED tenues hors des bandes
    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
    [bom.csv, cells-1.kicad_sch, chain.kicad_sch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]
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2026-09-17 Carte de banc fermée : éventail FPC et sorties du buck dessinés dans le générateur, connexité vérifiée au build
    Le DRC de KiCad comptait 31 connexions manquantes sur la carte de banc
    là où le build de boardgen en annonçait six. Cinq trous dans
    tools/boardgen/core.py, corrigés : couloir de sortie des vias
    d'éventail réclamé sans cuivre (le build dessine maintenant la piste
    du couloir jusqu'à la route), pastilles rondes et roundrect prises
    pour des rectangles (cellules d'arrivée et contrôle d'isolement sur la
    forme réelle), pastille déclarée atteinte sans preuve (vias comptés,
    pastille traversante en un seul groupe, sinon net ouvert), piste de
    puissance refusée le long d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
    [bench.kicad_pcb, bench.kicad_sch]
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2026-09-18 Quadrant 2 x 2 reroutée : 7 éléments non connectés au DRC de KiCad, contre 117
    La bande de frontal est reroutée sur la comptabilité de connexité
    partagée, avec la géométrie qui rendait le routage impossible corrigée
    à la racine (note 04) : bus réespacés pour qu'un via puisse les
    atteindre et prolongés jusqu'aux amplificateurs, plan de masse sur la
    couche arrière à la place du bus de masse, prises des cellules
    dessinées dans le générateur (masse, 5VA, référence, bus d'excitation,
    12 V, entrées d'aiguilleur, grille d'excitation), chaîne LED sortie de
    la bande par deux voies, placement du frontal par affinité.
    Le compte du build et celui de KiCad disent désormais la m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
    [cells-1.kicad_sch, chain.kicad_sch, leds.kicad_sch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]
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2026-09-19 Ce que sont les 28 restes de la maquette, et l'oscilloscope qu'il faut
    Le rapport DRC de la carte analogique de maquette nommait 28 éléments
    non connectés sans dire lesquels : le README les détaille maintenant
    net par net, dont les deux qui comptent vraiment, la masse du buck et
    son retour de tension.
    Le tuto du banc chiffrait l'oscilloscope au jugé. La bande de mesure
    fixe elle même les planchers : bande passante et cadence
    d'échantillonnage déduites de la note la plus haute, fenêtre d'écoute
    du firmware, amplitudes de la sonnerie. Un appareil de poche à une
    voie les tient ; ses deux limites, l'ondulation du buck et la lecture
    des notes au curseur, sont dites, avec le partage de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
2026-09-20 L'audit de commande devient un outil, tools/fabcheck.py
    L'audit fait à la main avant la commande donne le même verdict en une
    commande, sans KiCad ni réseau : contour, pile de couches, piste et via
    les plus petits, empreinte de l'archive contre la carte commitée,
    couverture du BOM d'assemblage, lignes sans code LCSC, et un verdict
    par carte. Code de sortie non nul si une archive ne correspond plus à
    sa carte, le seul défaut de cette famille qui rende une commande
    fausse plutôt qu'incomplète.
    Les pastilles ne sont plus comptées comme des composants : points de
    test, amarres de spirale et trous de fixation n'ont rien à
    s'approvisionner. Le quadrant 2 x 2 porte donc 118 composants, d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
2026-09-20 État mesuré des cartes de la phase 1, et le défaut de perçage
    Le DRC de KiCad sur les fichiers commités donne 141 éléments non
    connectés sur le cerveau, 69 sur la carte puissance, 51 sur l'horloge,
    27 sur la carte moteurs. Un net ouvert compte plusieurs éléments, d'où
    l'écart avec les nets ouverts que les builds annoncent.
    La carte moteurs porte en plus 24 perçages trop proches, de 0,03 à
    0,19 mm pour un minimum de 0,25 : même famille que les huit de la carte
    bobines, alors que le routeur tient un keepout de perçage autour de
    chaque pastille traversante. La cause n'est pas établie, donc aucune
    correction n'est écrite ; le constat est consigné.
    Les notes 13 et 16 renvoien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
2026-09-20 Carte analogique : placement, courtyards et routage à zéro défaut
    Les 49 chevauchements de courtyard sont corrigés dans le placement et
    le routage a été rejoué dessus. Le build vérifie maintenant cette
    famille lui même (tools/analoggen/yards.py) : il lit les courtyards des
    empreintes, les pose, compte les paires qui se recouvrent, exactement
    comme KiCad, et sort le nombre sur sa ligne d'état.
    Le replacement a rouvert des liaisons, fermées par des routes
    structurelles plutôt qu'une à une : la traversée de sa rangée par la
    ligne B de chaque cellule, face avant, dans le canal de 0,86 mm entre
    les deux rangées ; le contournement du coin sud-est, sans aucune
    pastille, pour la lig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
    [analog-board.kicad_pcb, analog-board.kicad_sch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]
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2026-10-04 Quadrant 4 x 4 : les amplificateurs s'échappent sous le boîtier, le rip-up n'échange jamais un net de bobine
    Les broches des SOIC-8 de la colonne d'amplification n'avaient aucune
    place pour un via : U5 et U7 se font face à un demi-millimètre, les
    broches est de U7 touchent les passifs de la bande est, celles de U8 le
    réseau de son étage. Chaque broche se prolonge donc sous le corps du
    boîtier jusqu'à un via dans une colonne par côté (soic_escapes), au pas
    de 1,27 mm une route passe entre deux vias ; la colonne est de U7 reste
    à l'écart du rail 3V3, celle de U8 tombe dans la fente de vias entre le
    bus de référence et le bus d'excitation, ses broches ouest partent vers
    l'espace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
2026-10-12 Note 25 : le plan de la maquette Hall + RFID, à commander chez JLCPCB
    Une carte de 2 x 2 cases à p = 50 (boucle NFC, lecteur MFRC522 et
    capteur Hall par case, multiplexeur, ESP32-S3 sur la carte, assemblage
    Standard), une planche d'étiquettes NFC à la taille du pion, des pièces,
    une plaque et des gabarits imprimés chez JLC3DP : tout se commande chez
    JLCPCB sauf les aimants, pour 265 à 420 EUR TTC estimés.
    - Onze questions chiffrées (M12 à M14) que la maquette tranche, dont
    les deux objections de l'ADR 0001 à la RFID.
    - Onze corrections à la note 24 : étiquette de 25 mm trop grande pour
    toute base, marge ISO indépendante de l'étiquette, courant d'antenne
    sous-estimé, pr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
2026-10-12 Lot 2 : la maquette Hall + RFID entre dans le yaml, nfc.antenna corrigée
    Section hall_rfid.mockup (cases, boucles par colonne, lecteurs par
    rangée, adaptation, chaîne Hall, brochage, étiquettes, aimants,
    impressions, quantités) et ses modèles ; DRV5055A3 ajouté aux
    capteurs, valeurs du DRV5053OA corrigées, décalage admissible de
    8 mm (D14), champ ISO maximal. Le diamètre intérieur de la boucle ne
    compte plus un écart de trop : L passe de 0,32 à 0,34 µH.
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2026-10-12 Notes 24 et 25 : erratum et valeurs du dépôt
    La note 24 porte un erratum (boucle NFC de 0,34 µH, DRV5053OA à
    2,7 mA et 35 µs, multiplexeur en SSOP-24, nappe 4 x 4 suspendue à
    M12b) et ses chiffres corrigés ; sa page et deux figures sont
    régénérées. La note 25 passe au statut de plan validé, lot 2 fait :
    ses valeurs préliminaires sont remplacées par celles du dépôt, avec la
    fonction qui les calcule, et les écarts qui changent une conclusion
    sont dits (amas à 0,10 p, étiquette P + 15 pF, variante G + 10 pF,
    couloir partagé par deux lecteurs). Journal et index mis à jour.
2026-10-12 Lot 2 : corrections de la relecture contradictoire
    - nfc : le champ de service s'obtient en relevant la résistance de
    sortie de l'émetteur, calée sur le champ le plus fort des positions
    admissibles ; marges, courants et niveau RX de service pour chaque
    étiquette de la planche ; garde du courant TVDD au champ de service
    pour toutes les variantes, à pleine conductance pour P nue seule ;
    garde sur le coefficient de réflexion ; Q lu au NanoVNA (vna_q) ;
    permittivité dans le yaml ;
    - hallrfid_mockup : gardes de la plage linéaire et de la pleine
    échelle pour le capteur et son remplaçant, ouverture de chaque case,
    broches du module, ordre de l'USB, signaux obligatoires ; b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
2026-10-12 Note 25 : budget du régulateur avec son courant propre
    Le paragraphe 4.5 reprend le budget corrigé à la relecture : 0,66 W
    sous 5 V, 0,75 W sous 5,25 V, jonction vers 107 °C, et 1,45 V de marge
    sous les 4,75 V d'un hôte USB pour 1,3 V de chute au plus.
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2026-10-17 Micrologiciel du démonstrateur Hall + RFID : pilote MFRC522, console, test hôte
    Pilote derrière une interface SPI abstraite, séquence ISO 14443A sur
    deux niveaux de cascade, états émission et tenu, conductance réglable,
    helpers Hall avec correction ratiométrique ; en-tête généré du yaml et
    vérifié par un test ; test hôte contre une puce simulée, lancé par la
    CI.
2026-10-17 Démonstrateur LC : nomenclature chiffrée, paniers et tutoriel (note 26)
    tools/demobom.py agrège les BOM des cartes de chaque démonstrateur avec
    les prix et liens de docs/prix-demonstrateur.csv (relevés web du jour)
    et écrit la fiche, le CSV et les paniers LCSC et Mouser. La note 26
    explique les composants, leurs interactions, la commande, le montage et
    les tests du démonstrateur par oscillations.
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
